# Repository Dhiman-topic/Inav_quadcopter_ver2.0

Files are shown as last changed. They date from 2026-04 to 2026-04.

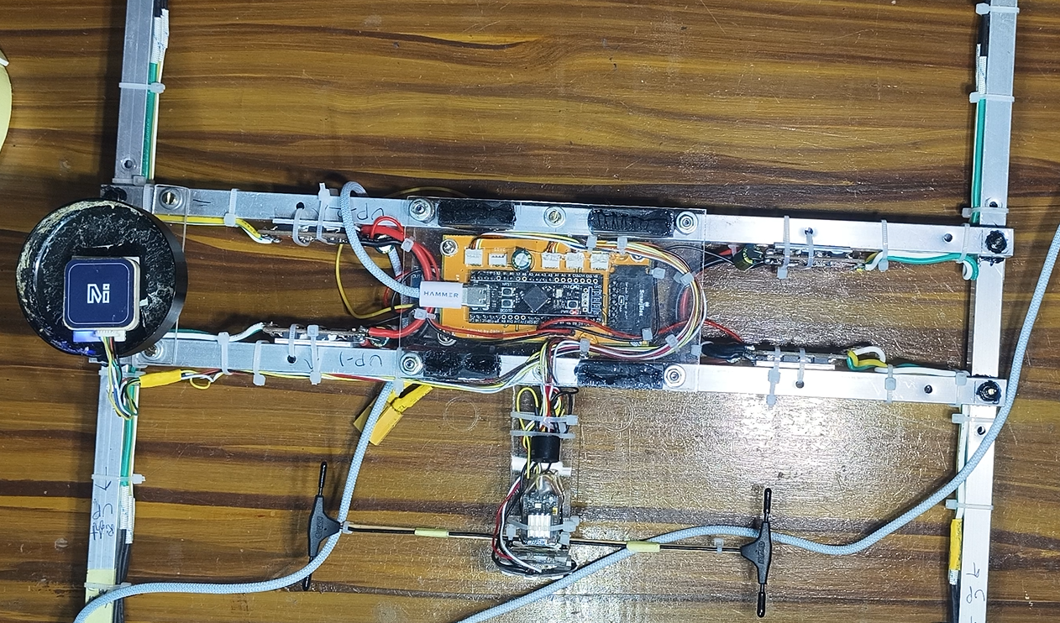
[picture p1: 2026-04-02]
images/build/Mounted_electronics.png

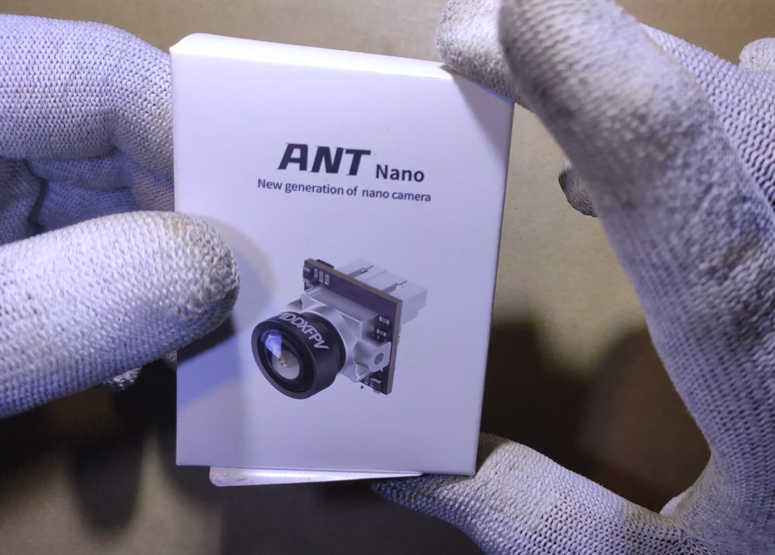
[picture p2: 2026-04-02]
images/build/fpv_CAMERA.png

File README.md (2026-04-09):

# Inav\_quadcopter\_ver2.0

A custom-built quadcopter with a self-designed flight controller running iNav 7.1.1, mounted on a lightweight custom aluminium frame.

Compact and powerful **STM32F411CE based flight controller** designed for **INAV firmware**.

This controller supports multiple IMU sensors and provides essential interfaces for GPS, receivers, ESCs, telemetry and peripherals.

# ⚡ Power Requirements

1. The flight controller **must be powered with a stable 5V DC supply**.

2\. Most ESCs include a **5V BEC (Battery Eliminator Circuit)** that can be used to power the flight controller.

### ⚠️ Important Warning

* The flight controller **must not be powered directly from battery voltage**.
* Only use a **stable 5V DC supply**.

Supplying incorrect voltage may **permanently damage the flight controller**.

Always verify the output voltage of your BEC before connecting it to the FC.

# ✈️ Features

* STM32F411CE MCU
* Supported IMU sensors

  * MPU9250
  * MPU6500
  * BMI160
* BMP280 Barometer
* MAX7456 OSD
* 2 Hardware UART ports
* SoftSerial support
* I2C bus for compass and peripherals
* WS2811 LED strip support
* Up to **6 motor outputs**
* Additional **servo outputs**
* Battery voltage monitoring
* Current sensing
* RSSI analog input
* Airspeed sensor input

\---

# 📦 Firmware

This flight controller runs **INAV Firmware**.

Download firmware:  inav\_xxx\_STM32F411CE.zip

`xxx` = firmware version number.

Example: inav\_7.1.1\_STM32F411CE.zip

\---

# 🖥 INAV Configurator

Download the configurator matching the firmware version.

https://github.com/iNavFlight/inav-configurator/releases

Example:

|Firmware|Configurator|
|-|-|
|INAV 7.x|Configurator 7.x|

Extract the ZIP file and run: inav-configurator.exe

\---

# 🔌 Enter DFU Mode

To flash firmware, the flight controller must be in **DFU mode**.

### Steps

1️⃣ Locate the **BOOT0 button** on the board

2️⃣ Press and **hold BOOT0**

3️⃣ Connect the USB cable to your PC

4️⃣ Release the button

If successful, **DFU** will appear in the configurator connection menu.

\---

# ⚠ DFU Driver Fix

If DFU does not appear, install drivers using:

https://impulserc.blob.core.windows.net/utilities/ImpulseRC\_Driver\_Fixer.exe

Run the program and allow it to install the required drivers.

\---

# ✅ Successful Installation

If flashing is successful:

* wait a few seconds
* the **blue LED will start blinking**

🎉 Firmware installed successfully.

\---

# ⚙ Recommended Setup Steps

After flashing firmware:

1. Calibrate accelerometer
2. Calibrate compass
3. Configure receiver
4. Configure motor outputs
5. Setup GPS (if used)
6. Setup flight modes

\---

# 🔗 Useful Links

INAV Official Website

https://inavflight.com

INAV GitHub

https://github.com/iNavFlight

INAV Documentation

https://github.com/iNavFlight/inav/wiki

\---

# 📜 License

This project is **licensed under the GNU General Public License** and is intended to support the INAV ecosystem.

\---

# ❤️ Acknowledgements

Special thanks to the **INAV community** and developers and **Rıza Çelik** for their continuous work on the firmware.

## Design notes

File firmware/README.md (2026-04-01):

# Firmware — iNav 7.1.1

## Download
Get iNav 7.1.1 from the official releases:
https://github.com/iNavFlight/inav/releases/tag/7.1.1

Pick the `.hex` file matching your MCU (STM32F405 for this FC).

## Flash
1. Open [iNav Configurator](https://github.com/iNavFlight/inav-configurator/releases)
2. Connect FC via USB
3. Go to **Firmware Flasher**
4. Load the `.hex` file and click **Flash Firmware**

## Restore Configuration
1. In iNav Configurator, open the **CLI** tab
2. Copy the full contents of `inav_config/quadcopter_inav_7.1.1.diff`
3. Paste into the CLI input box and press Enter
4. Type `save` and press Enter
5. Power cycle the FC

## Notes
- Always re-calibrate the accelerometer after restoring config
- GPS baud rate is set to auto — M10 Ultra will be detected at 38400 or 115200
- VTX settings are for 5.8GHz band 5 channel 8 (Raceband R8)

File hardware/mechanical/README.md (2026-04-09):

# Mechanical / Frame Files

## Frame Specs
- Material: 6061-T6 aluminium, 3mm thick
- Motor-to-motor diagonal: 520 mm
- Estimated frame weight: 180 g

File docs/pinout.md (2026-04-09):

# FC Pinout Reference

## Motor / ESC Signal Outputs

|Pin|Motor|Position|Rotation|
|-|-|-|-|
|M1|ESC 1|Rear-Right|CW|
|M2|ESC 2|Front-Right|CCW|
|M3|ESC 3|Rear-Left|CCW|
|M4|ESC 4|Front-Left|CW|

All ESC signal lines are 3.3V PWM at 400Hz (SimonK standard).

## UART Assignments

|UART|Function|Baud|
|-|-|-|
|UART1|GPS (M10 Ultra)||
|UART2|ELRS / CRSF RX||
|UART3|||
|||—|

## I2C Bus

|Address|Device|
|-|-|
|0x76|DPS310 Barometer|

## SPI Bus

|Device|CS Pin|
|-|-|
|BMI160|PB12|

## Power Rails

|Rail|Source|Used for|
|-|-|-|
|5V|Battery in|FC,IMU, Baro, SPI/I2C devices, GPS, RX|
||||

## LED Indicators

|LED|Color|Meaning|
|-|-|-|
|LED1 (WS2812B)|Red|Armed|
|LED2 (WS2812B)|Green BLINK|GPS fix acquired|

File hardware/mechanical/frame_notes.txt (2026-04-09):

# Frame — Mechanical Notes

## Material
- **Alloy**: 6061-T6 Aluminium hollow square bar
- **Cross-section** : 10sqmm
- **Thickness**: 1mm
- **Arm width**: 20mm

## Dimensions
- **Wheelbase**: 520mm (motor-to-motor diagonal)
- **Arm length**: ~400mm each
- **Centre Arm length**: 360mm
- **Motor mount hole pattern**: 16mm × 19mm (2212 motor standard)

## Weight (estimated)
| Part | Weight  |
|---|---|
| 4× Arms | ~160g |
| Hardware (screws) | ~20g |
| **Total frame** | **~180g** |

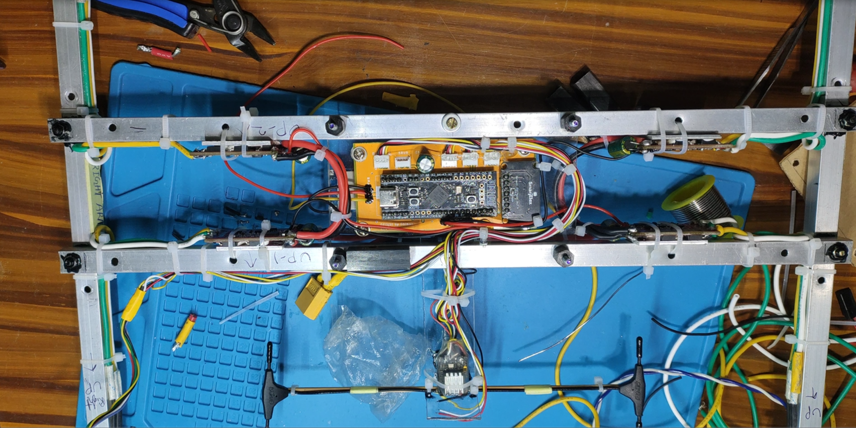
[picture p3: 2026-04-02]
images/build/Electronics_on_board.png

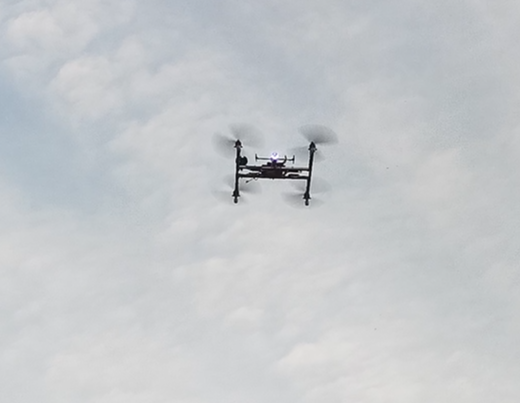
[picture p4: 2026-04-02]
images/flight/Gps_hold_position.png

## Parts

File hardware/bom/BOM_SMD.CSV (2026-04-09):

Part | Value | Device | Package | Description | AVAILABILITY | BOM | CHECK_PRICES | DESCRIPTION | MF | MP | MPN | OC_FARNELL | OC_NEWARK | PACKAGE | POPULARITY | PRICE | PROD_ID | SNAPEDA_LINK | SPICEPREFIX | TP_SIGNAL_NAME | VALUE
ACCELEROMETER |  | PINHD-1X7 | 1X07 | PIN HEADER |  |  |  |  |  |  |  |  |  |  | 0
BAROMETER |  | PINHD-1X7 | 1X07 | PIN HEADER |  |  |  |  |  |  |  |  |  |  | 0
BUZZ_LED | BUZZ_LED | 53048-04 | 53048-04 | CONNECTOR |  |  |  |  | MOLEX |  | 53048-0410 | 1462887 | 57H4721 |  | 0
C1 |  | CPOL-EUE3.5-8 | E3,5-8 | POLARIZED CAPACITOR, European symbol |  |  |  |  |  |  |  |  |  |  | 13 |  |  |  | C
C2 | 12pF | C-EUC0603 | C0603 | CAPACITOR, European symbol |  |  |  |  |  |  |  |  |  |  | 73 |  |  |  | C
C3 | 12pF | C-EUC0603 | C0603 | CAPACITOR, European symbol |  |  |  |  |  |  |  |  |  |  | 73 |  |  |  | C
C4 | 12pF | C-EUC0603 | C0603 | CAPACITOR, European symbol |  |  |  |  |  |  |  |  |  |  | 73 |  |  |  | C
C5 | 12pF | C-EUC0603 | C0603 | CAPACITOR, European symbol |  |  |  |  |  |  |  |  |  |  | 73 |  |  |  | C
C6 | 100nF | C-EUC0603 | C0603 | CAPACITOR, European symbol |  |  |  |  |  |  |  |  |  |  | 73 |  |  |  | C
C7 | 2.2uF | C-EUC0603 | C0603 | CAPACITOR, European symbol |  |  |  |  |  |  |  |  |  |  | 73 |  |  |  | C
C8 | 100nF | C-EUC0603 | C0603 | CAPACITOR, European symbol |  |  |  |  |  |  |  |  |  |  | 73 |  |  |  | C
C9 | 1uF | C-EUC0603 | C0603 | CAPACITOR, European symbol |  |  |  |  |  |  |  |  |  |  | 73 |  |  |  | C
C10 | 100nF | C-EUC0603 | C0603 | CAPACITOR, European symbol |  |  |  |  |  |  |  |  |  |  | 73 |  |  |  | C
C11 | 100nf | C-EUC0603 | C0603 | CAPACITOR, European symbol |  |  |  |  |  |  |  |  |  |  | 73 |  |  |  | C
C12 | 100nF | C-EUC0603 | C0603 | CAPACITOR, European symbol |  |  |  |  |  |  |  |  |  |  | 73 |  |  |  | C
C13 | 1uF | C-EUC0603 | C0603 | CAPACITOR, European symbol |  |  |  |  |  |  |  |  |  |  | 73 |  |  |  | C
C14 | 1uF | C-EUC0603 | C0603 | CAPACITOR, European symbol |  |  |  |  |  |  |  |  |  |  | 73 |  |  |  | C
C15 | 100nf | C-EUC0805 | C0805 | CAPACITOR, European symbol |  |  |  |  |  |  |  |  |  |  | 88 |  |  |  | C
C16 | 10uf | C-EUC0805 | C0805 | CAPACITOR, European symbol |  |  |  |  |  |  |  |  |  |  | 88 |  |  |  | C
C17 | 10uf | C-EUC0805 | C0805 | CAPACITOR, European symbol |  |  |  |  |  |  |  |  |  |  | 88 |  |  |  | C
C18 | 10uf | C-EUC0805 | C0805 | CAPACITOR, European symbol |  |  |  |  |  |  |  |  |  |  | 88 |  |  |  | C
C19 | 10uf | C-EUC0805 | C0805 | CAPACITOR, European symbol |  |  |  |  |  |  |  |  |  |  | 88 |  |  |  | C
C20 | 100nf | C-EUC0805 | C0805 | CAPACITOR, European symbol |  |  |  |  |  |  |  |  |  |  | 88 |  |  |  | C
C21 | 100nf | C-EUC0805 | C0805 | CAPACITOR, European symbol |  |  |  |  |  |  |  |  |  |  | 88 |  |  |  | C
C28 | 100nF | C-EUC0603 | C0603 | CAPACITOR, European symbol |  |  |  |  |  |  |  |  |  |  | 73 |  |  |  | C
C29 | 100nF | C-EUC0603 | C0603 | CAPACITOR, European symbol |  |  |  |  |  |  |  |  |  |  | 73 |  |  |  | C
COMPASS | COMPASS | 53048-04 | 53048-04 | CONNECTOR |  |  |  |  | MOLEX |  | 53048-0410 | 1462887 | 57H4721 |  | 0
D1 |  | DIODESOD-123 | SOD-123 | Diode
D2 |  | DIODESOD-123 | SOD-123 | Diode
ELRS-RX | 53048-04 | 53048-04 | 53048-04 | CONNECTOR |  |  |  |  | MOLEX |  | 53048-0410 | 1462887 | 57H4721 |  | 0
GPS | 53048-04 | 53048-04 | 53048-04 | CONNECTOR |  |  |  |  | MOLEX |  | 53048-0410 | 1462887 | 57H4721 |  | 0
JP1 |  | PINHD-1X3 | 1X03 | PIN HEADER |  |  |  |  |  |  |  |  |  |  | 92
JP2 |  | PINHD-1X4 | 1X04 | PIN HEADER |  |  |  |  |  |  |  |  |  |  | 91
L1 | l | L-EUL2012C | L2012C | INDUCTOR, European symbol |  |  |  |  |  |  |  |  |  |  | 2 |  |  |  | L
LED1 |  | LEDCHIPLED_1206 | CHIPLED_1206 | LED
LED2 |  | LEDCHIPLED_1206 | CHIPLED_1206 | LED
LEDBUZ | 53048-04 | 53048-04 | 53048-04 | CONNECTOR |  |  |  |  | MOLEX |  | 53048-0410 | 1462887 | 57H4721 |  | 0
LIDAR | 53048-04 | 53048-04 | 53048-04 | CONNECTOR |  |  |  |  | MOLEX |  | 53048-0410 | 1462887 | 57H4721 |  | 0
MAG | 53048-04 | 53048-04 | 53048-04 | CONNECTOR |  |  |  |  | MOLEX |  | 53048-0410 | 1462887 | 57H4721 |  | 0
MOTOR |  | PINHD-1X6 | 1X06 | PIN HEADER |  |  |  |  |  |  |  |  |  |  | 79
MOTOR1 | 53048-04 | 53048-04 | 53048-04 | CONNECTOR |  |  |  |  | MOLEX |  | 53048-0410 | 1462887 | 57H4721 |  | 0
NAV | NAVIGATION | 53048-04 | 53048-04 | CONNECTOR |  |  |  |  | MOLEX |  | 53048-0410 | 1462887 | 57H4721 |  | 0
PWR |  | PINHD-1X3/OCT | 1X03/OCT | PIN HEADER
R3 | 10k | R-US_R0603 | R0603 | RESISTOR, American symbol |  |  |  |  |  |  |  |  |  |  | 77 |  |  |  | R
R4 | 10k | R-US_R0603 | R0603 | RESISTOR, American symbol |  |  |  |  |  |  |  |  |  |  | 77 |  |  |  | R
R5 | 330 | R-EU_R0603 | R0603 | RESISTOR, European symbol |  |  |  |  |  |  |  |  |  |  | 70 |  |  |  | R
R6 | NRST | R-EU_R0603 | R0603 | RESISTOR, European symbol |  |  |  |  |  |  |  |  |  |  | 70 |  |  |  | R
R7 | 1K | R-EU_R0603 | R0603 | RESISTOR, European symbol |  |  |  |  |  |  |  |  |  |  | 70 |  |  |  | R
R8 | 1K | R-EU_R0603 | R0603 | RESISTOR, European symbol |  |  |  |  |  |  |  |  |  |  | 70 |  |  |  | R
R10 | 10k | R-EU_R0603 | R0603 | RESISTOR, European symbol |  |  |  |  |  |  |  |  |  |  | 70 |  |  |  | R
R11 | 10k | R-EU_R0603 | R0603 | RESISTOR, European symbol |  |  |  |  |  |  |  |  |  |  | 70 |  |  |  | R
R12 | 10k | R-EU_R0603 | R0603 | RESISTOR, European symbol |  |  |  |  |  |  |  |  |  |  | 70 |  |  |  | R
R13 | 10k | R-EU_R0603 | R0603 | RESISTOR, European symbol |  |  |  |  |  |  |  |  |  |  | 70 |  |  |  | R
R14 | 10k | R-EU_R0603 | R0603 | RESISTOR, European symbol |  |  |  |  |  |  |  |  |  |  | 70 |  |  |  | R
R15 | 10k | R-EU_R0603 | R0603 | RESISTOR, European symbol |  |  |  |  |  |  |  |  |  |  | 70 |  |  |  | R
R16 | 10k | R-EU_R0603 | R0603 | RESISTOR, European symbol |  |  |  |  |  |  |  |  |  |  | 70 |  |  |  | R
R17 |  | R-EU_R0603 | R0603 | RESISTOR, European symbol |  |  |  |  |  |  |  |  |  |  | 70 |  |  |  | R
R18 |  | R-EU_R0603 | R0603 | RESISTOR, European symbol |  |  |  |  |  |  |  |  |  |  | 70 |  |  |  | R
R19 | 10k | R-EU_R0603 | R0603 | RESISTOR, European symbol |  |  |  |  |  |  |  |  |  |  | 70 |  |  |  | R
RXTX | receiver | 53048-04 | 53048-04 | CONNECTOR |  |  |  |  | MOLEX |  | 53048-0410 | 1462887 | 57H4721 |  | 0
SERVO | 53048-04 | 53048-04 | 53048-04 | CONNECTOR |  |  |  |  | MOLEX |  | 53048-0410 | 1462887 | 57H4721 |  | 0
SJ1 |  | SOLDERJUMPER | SOLDERJUMPER_ARROW_NOPASTE | SMD Solder JUMPER |  | EXCLUDE
SJ2 |  | SOLDERJUMPER | SOLDERJUMPER_ARROW_NOPASTE | SMD Solder JUMPER |  | EXCLUDE
SRVO | SRVO | 53048-04 | 53048-04 | CONNECTOR |  |  |  |  | MOLEX |  | 53048-0410 | 1462887 | 57H4721 |  | 0
TP1 | TPB1,27 | TPB1,27 | B1,27 | Test pad |  |  |  |  |  |  |  |  |  |  | 19
U$1 | BLACKPILL_FR_INAV7.1 | BLACKPILL_FR_INAV7.1 | BLACKPILLBOARD
U1 | STM32F411CEU6 | STM32F411CEU6 | QFN50P700X700X60-49N | Check availability | In Stock |  | https://www.snapeda.com/parts/STM32F411CEU6/STMicroelectronics/view-part/?ref=eda | ARM® Cortex®-M4 STM32F4 Microcontroller IC 32-Bit Single-Core 100MHz 512KB (512K x 8) FLASH 48-UFQFPN (7x7) | STMicroelectronics | STM32F411CEU6 |  |  |  | UFQFPN-48 STMicroelectronics |  | None |  | https://www.snapeda.com/parts/STM32F411CEU6/STMicroelectronics/view-part/?ref=snap
U2 | DPS310 | DPS310 | XDCR_DPS310 | Check availability | Not in stock |  | https://www.snapeda.com/parts/DPS310/Infineon/view-part/?ref=eda | Pressure Sensor 4.35PSI ~ 17.4PSI (30kPa ~ 120kPa) Vented Gauge - 24 b 8-VFLGA | Infineon Technologies | DPS310 |  |  |  | VFLGA-8 Infineon Technologies |  | None |  | https://www.snapeda.com/parts/DPS310/Infineon/view-part/?ref=snap
U3 | BMI160 | BMI160 | PQFN50P250X300X88-14N | Check availability | In Stock |  | https://www.snapeda.com/parts/BMI160/Bosch/view-part/?ref=eda | BMI160 series Accelerometer, Gyroscope, 6 Axis Sensor Evaluation Board | Bosch | BMI160 |  |  |  | LGA-14 Bosch |  | None |  | https://www.snapeda.com/parts/BMI160/Bosch/view-part/?ref=snap
U4 |  | VREG_SOT23-5 | SOT23-5 | SOT23-5 Fixed Voltage Regulators
U5 | W25Q32JVSSIQ | W25Q32JVSSIQ | SOIC127P790X216-8N | Check availability | In Stock |  | https://www.snapeda.com/parts/W25Q32JVSSIQ-TR/Winbond/view-part/?ref=eda | FLASH - NOR Memory IC 32Mb (4M x 8) SPI - Quad I/O 133 MHz 8-SOIC | Winbond | W25Q32JVSSIQ-TR |  |  |  | None |  | None |  | https://www.snapeda.com/parts/W25Q32JVSSIQ-TR/Winbond/view-part/?ref=snap
U6 |  | VREG_SOT23-5 | SOT23-5 | SOT23-5 Fixed Voltage Regulators
U7 |  | VREG_SOT23-5 | SOT23-5 | SOT23-5 Fixed Voltage Regulators
Y1 | 32.768kHz | CRYSTAL-32.768KHZSMD-3.2X1.5 | CRYSTAL-SMD-3.2X1.5MM | 32.768kHz Crystal |  |  |  |  |  |  |  |  |  |  |  |  | XTAL-13062 |  |  |  | 32.768kHz
Y2 | 25MHz | CRYSTAL-25MHZ-SMD-2.0X1.6MM | CRYSTAL-SMD-2.0X1.6MM | 25MHz Crystal |  |  |  |  |  |  |  |  |  |  |  |  | XTAL-16235 |  |  |  | 25MHz

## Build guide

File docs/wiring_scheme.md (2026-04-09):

## Connection Summary

```
[4200mAh Li-Ion 3S]
        │
        ├──► [4× SimonK 30A ESC] ──► [2212 920KV Motors]
        │         │ (Signal wire)
        │         └──► FC Motor Pads M1–M4
        │
        └──► [FC VBAT pad] ──► Onboard 5V BEC
                                      │
                    ┌─────────────────┼──────────────────────┐
                    │                 │                      │
              [M10 Ultra GPS]  [GEPrc ELRS RX]    [1.2W 5.8G VTX]
               UART1 TX/RX      UART2 TX/RX        5V + GND + Video
```

## Notes
- Run the video signal wire away from ESC power wires to reduce interference
- Twist VBAT and GND wires from battery to ESCs to reduce EMI
- GPS should be mounted on a mast at least 3cm above the FC for best reception
- ELRS receiver antenna should be at 90° to each other for diversity coverage

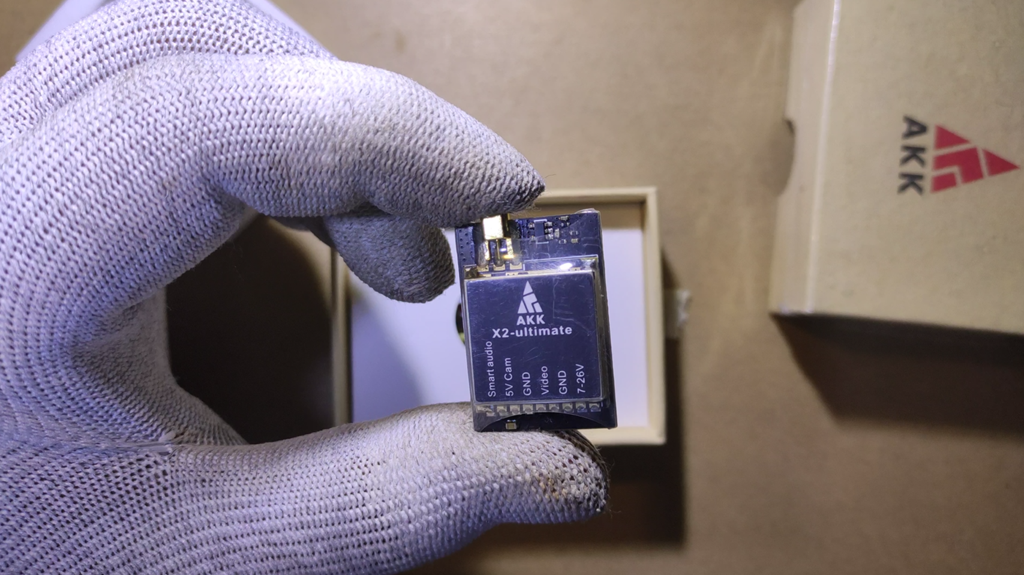
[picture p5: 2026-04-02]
images/build/VTX.png

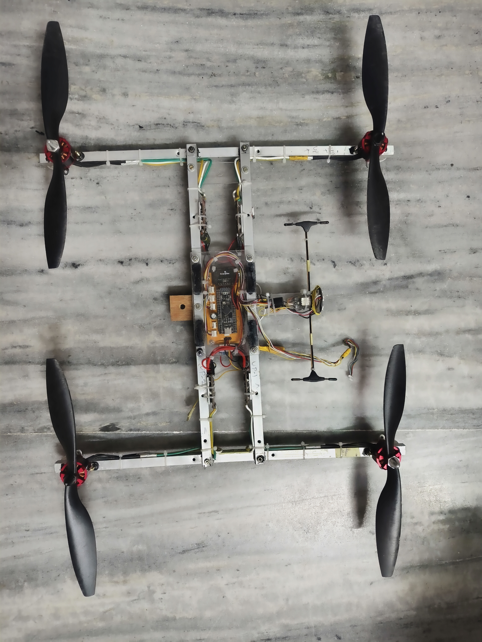
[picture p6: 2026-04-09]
images/build/Build_picture_2.jpg

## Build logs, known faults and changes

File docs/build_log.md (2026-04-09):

# Build Log

## Phase 1 — Frame Design \& Cutting

* Designed custom aluminium frame in CAD
* Material: 1sqmm 6061-T6 hollow square
* Frame cut at home
* Wheelbase: 520mm diagonal

## Phase 2 — FC PCB Design

* Designed custom FC in Eagle
* MCU: STM32F411CEU6
* IMU: BMI160 (SPI)
* Baro: DPS310 (I2C)
* Mag : HMC5883L(I2C)
* Ordered from JLCPCB — 5 boards
* First board assembled and USB DFU boot confirmed

## Phase 3 — Firmware

* Flashed iNav 7.1.1
* BMI160 and DPS310 detected successfully
* GPS (M10 Ultra with Mag. sensor) locked within 90 seconds outdoors

## Phase 4 — Assembly

* Motors and ESCs mounted and soldered
* SimonK ESC calibration done (all at once via FC)
* ELRS receiver bound to transmitter (ExpressLRS 2.4GHz)
* VTX tested — clean 5.8GHz video on band 5 ch 8

## Phase 5 — First Flight

* Maiden flight in Angle mode
* Stable hover, minor yaw drift
* GPS RTH tested and working
* Flight time: \~24 minutes at 60% throttle hover

## TODO

* \[ ] Tune PIDs for sport mode
* \[ ] Add OSD overlay
* \[ ] Test autonomous waypoint mission
